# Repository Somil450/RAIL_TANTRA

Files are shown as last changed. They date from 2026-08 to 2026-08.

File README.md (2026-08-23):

# 🚂 Smart Train 3D — Complete Electric Locomotive Assembly Kit

> A fully parametric, 3D-printable modern electric train designed with **CadQuery**.
> The complete 3-car configuration (Locomotive + 2 Wagons) fits within **588 mm** total length.

---

## 📸 Preview


> present in output/SMART_TRAIN_FINAL.step



> present in output/COMPLETE_TRAIN_V3_OPENROOF.step

---

## 🎯 Design Goals

| Goal | Value |
|---|---|
| Total assembled length | ≤ 600 mm → **588 mm** ✅ |
| Locomotive length | 200 mm |
| Each wagon length | 180 mm |
| Inter-vehicle gap | 14 mm (coupler space) |
| Body width | **102 mm (10.2 cm)** |
| Body height | **~102 mm (10.2 cm)** |
| Wheel diameter | **15 mm (1.5 cm)** |
| Roof | **OPEN** (accessible interior) |
| Wheel motion | Spinning (free on axle) |
| Bogie motion | Rotating pivot-pin (for curves) |
| Vehicle connection | Articulated drawbar + pivot bracket |

---

## 🏗️ Design & Architecture

### How we built it

The train was designed **iteratively** using Python + [CadQuery](https://cadquery.readthedocs.io/) — a parametric 3D CAD scripting library. All geometry is defined through master parameters at the top of each script, making it easy to resize any part.

#### Evolution of the design:

```
v1  →  Individual component files (chassis.py, wheel.py, etc.)
v2  →  Merged single-file assembly (COMPLETE_TRAIN_V2)
v3  →  Open roof, wider body (102mm) — COMPLETE_TRAIN_V3
v4  →  Separate movable-wheel files (TRAIN_BODY + WHEEL + AXLE)
v5  →  J-hook couplers, single merged file (FINAL_TRAIN)
v6  →  Full assembly kit: rotating bogies + pivot-drawbar couplers
```

### Key mechanical decisions

#### 1. Rotating Bogies (for cornering)
Each bogie has a **12 mm pivot pin** that sticks up through a **12.4 mm hole** in the chassis underframe. The 0.2 mm clearance per side lets the bogie swivel freely, so the train can navigate curves.

```
Chassis floor (Z = 0)
   ┌──────[12.4mm hole]──────┐
   │                         │
   └─────────────────────────┘
              ↕ swivels
   ┌──────[12.0mm pin]───────┐   ← bogie pivot pin
   │       BOGIE FRAME       │
   │  ┌─leg─┐         ┌─leg─┐│
   │  │axle │ ← → axle│     ││
   │  └─────┘         └─────┘│
   └─────────────────────────┘
        O   O           O   O    ← wheels (15mm dia)
```

#### 2. Articulated Drawbar Coupler (instead of rigid joints)
Between each pair of vehicles:

```
LOCO end ──[pivot bracket]──[drawbar]──[pivot bracket]── WAGON end
              ↑ 5mm pin                  ↑ 5mm pin
              ↓ 5.4mm fork hole          ↓ 5.4mm fork hole
```

- The **pivot bracket** mounts on the inner vehicle face with a 5 mm vertical pin
- The **drawbar** has fork holes (5.4 mm = 0.2 mm clearance → rotates freely)
- A thin mid-section on the drawbar acts as a **flex spring** for slight buffer action

#### 3. Spinning Wheels (FDM clearance)

| Component | Diameter | Fit type |
|---|---|---|
| Axle shaft | 5.0 mm | — |
| Bogie axle-box hole | 5.0 mm nominal | Press-fit (tight) |
| Wheel bore | 5.8 mm | +0.4 mm clearance → **spins freely** |
| Bogie pivot pin | 12.0 mm | — |
| Chassis pivot hole | 12.4 mm | +0.2 mm → **rotates freely** |

---

## 📁 File Structure

```
smart_train_3d/
│
├── 📄 README.md                  ← This file
├── 📄 requirements.txt           ← Python dependencies
│
├── 🐍 SCRIPTS — Build scripts (run these to generate STL/STEP)
│   ├── build_assembly_kit.py     ← ⭐ RECOMMENDED: Generates all 7 separate parts
│   ├── build_final_train.py      ← Single merged file (J-hooks, open roof)
│   ├── build_movable_wheels.py   ← Body + separate wheel + axle files
│   ├── build_complete_train_v3.py← Open roof, 102mm wide, single file
│   ├── build_complete_train_v2.py← Full closed train, single merged file
│   └── build_assembled_train.py  ← Earlier assembled version
│
├── 🐍 COMPONENT MODULES (used by early build scripts)
│   ├── parameters.py             ← All master dimensions
│   ├── chassis.py                ← Chassis underframe
│   ├── body_shell.py             ← Main body shell
│   ├── front_cab.py              ← Aerodynamic cab nose
│   ├── roof.py                   ← Roof panels + HVAC housings
│   ├── bogie.py                  ← Bogie frame geometry
│   ├── wheel.py                  ← Wheel disc + flange
│   ├── axle.py                   ← Axle shaft
│   ├── bearing_housing.py        ← Axle bearing blocks
│   ├── suspension.py             ← Suspension bolster
│   ├── brakes.py                 ← Brake shoe geometry
│   ├── coupler.py                ← Coupler head geometry
│   ├── pantograph.py             ← Roof pantograph structure
│   ├── internal_frame.py         ← Internal structural frame
│   └── TrainLayout.fs            ← Onshape FeatureScript (alternative CAD)
│
└── 📦 output/                    ← All generated STL and STEP files
    │
    ├── 🏆 FINAL / RECOMMENDED FILES
    │   ├── FINAL_TRAIN.stl       ← Complete train, J-hooks, open roof, 15mm wheels
    │   ├── FINAL_TRAIN.step      ← Same, in STEP format (Onshape/Fusion 360)
    │   ├── TRAIN_BODY.stl        ← Body only (no wheels) — for separate-parts printing
    │   ├── WHEEL_15mm.stl        ← Single 15mm wheel — print 24×
    │   └── AXLE_88mm.stl         ← Single axle — print 12×
    │
    ├── 🔄 VERSION HISTORY
    │   ├── COMPLETE_TRAIN_V3_OPENROOF.stl  ← V3: open roof, 102mm wide
    │   ├── COMPLETE_TRAIN_V3_OPENROOF.step
    │   ├── COMPLETE_TRAIN_V2.stl           ← V2: closed roof, 22 parts merged
    │   ├── COMPLETE_TRAIN_V2.step
    │   ├── SMART_TRAIN_COMPLETE.stl        ← V1: original assembled train
    │   └── SMART_TRAIN_COMPLETE.step
    │
    └── 🔩 INDIVIDUAL LOCO COMPONENTS (V1 separate parts)
        ├── 01_chassis.stl / .step
        ├── 02_internal_frame.stl / .step
        ├── 03_body_shell.stl / .step
        ├── 04_front_cab.stl / .step
        ├── 05_roof.stl / .step
        ├── 06_bogie.stl / .step
        ├── 07_wheel.stl / .step
        ├── 08_axle.stl / .step
        ├── 09_bearing_housing.stl / .step
        ├── 10_suspension.stl / .step
        ├── 11_brakes.stl / .step
        ├── 12_coupler.stl / .step
        └── 13_pantograph.stl / .step
```

---

## 🚀 How to Run It Yourself

### Prerequisites

- **Python 3.9+**  (tested on 3.10 and 3.11)
- **CadQuery 2.3+**

### Step 1 — Clone the repo

```bash
git clone https://github.com/Somil450/smart_train_3d.git
cd smart_train_3d
```

### Step 2 — Install dependencies

**Option A — pip (simplest):**
```bash
pip install -r requirements.txt
```

**Option B — conda (if pip fails on Windows):**
```bash
conda install -c conda-forge -c cadquery cadquery
```

### Step 3 — Generate the STL files

**To get the full final train in one file:**
```bash
python build_final_train.py
```
→ Outputs `output/FINAL_TRAIN.stl` and `output/FINAL_TRAIN.step`

**To get separate printable parts (recommended for assembly):**
```bash
python build_assembly_kit.py
```
→ Outputs `output/kit/` with 7 separate part files

**To get body + separate spinning wheels:**
```bash
python build_movable_wheels.py
```
→ Outputs `TRAIN_BODY.stl`, `WHEEL_15mm.stl`, `AXLE_88mm.stl`

### Step 4 — Open in 3D Viewer

On **Windows**, just double-click any `.stl` file — Windows 3D Viewer opens automatically.

Or import the `.step` file into:
- [Onshape](https://www.onshape.com) (free, browser-based)
- [Fusion 360](https://www.autodesk.com/products/fusion-360)
- [FreeCAD](https://www.freecad.org) (free, desktop)

---

## 🖨️ 3D Printing Guide

### Which file to print?

| Use case | File | Count |
|---|---|---|
| Quick single-piece print | `FINAL_TRAIN.stl` | 1× |
| Full assembly with spinning wheels | `TRAIN_BODY.stl` + `WHEEL_15mm.stl` + `AXLE_88mm.stl` | 1× + 24× + 12× |
| Full articulated kit (rotating bogies) | Run `build_assembly_kit.py` → print all 7 parts | See table below |

### Assembly kit print counts

| File | Part | Print |
|---|---|---|
| `01_LOCO_BODY.stl` | Locomotive body (open top) | 1× |
| `02_WAGON_BODY.stl` | Wagon body (identical for both wagons) | 2× |
| `03_BOGIE_FRAME.stl` | Rotating bogie with pivot pin | 6× |
| `04_WHEEL_15mm.stl` | 15 mm wheel disc | 24× |
| `05_AXLE.stl` | 88 mm axle shaft | 12× |
| `06_PIVOT_BRACKET.stl` | Coupler mounting bracket | 4× |
| `07_DRAWBAR.stl` | Articulating drawbar (flex spring) | 2× |

### Recommended print settings

| Setting | Value |
|---|---|
| Layer height | 0.2 mm |
| Infill | 20–30 % |
| Perimeters | 3 |
| Material | PLA or PETG |
| Supports | Required for bogie legs and coupler brackets |
| Bed adhesion | Brim recommended |

### Assembly order

```
Step 1 → Press axle into bogie axle-box holes        (5mm shaft → 5mm hole, tight grip)
Step 2 → Slide 2 wheels onto each axle end            (5.8mm bore → spins on 5mm axle)
Step 3 → Insert bogie pivot pin up into chassis hole  (12mm pin → 12.4mm hole, swivels)
Step 4 → Mount pivot brackets on inner vehicle ends
Step 5 → Clip drawbar fork holes onto bracket pins    (5.4mm hole → 5mm pin, rotates)
Step 6 → Repeat for both inter-vehicle junctions
```

---

## 🔧 Customising Dimensions

All master parameters are at the top of each build script. Key ones:

```python
TW   = 102     # Body width (Y), mm
WD   = 15      # Wheel diameter, mm
GA   = 62      # Track gauge (wheel inner face to inner face), mm
LL   = 200     # Locomotive length, mm
WL   = 180     # Wagon length, mm
GAP  = 14      # Inter-vehicle gap, mm
WALL = 3.0     # Body wall thickness, mm
AZ   = -24     # Axle centre Z (below chassis), mm
```

Change any of these and re-run the script — all geometry rebuilds automatically.

---

## 📐 Final Dimensions

```
┌───────────────────────────────────────────────────────────────┐
│  LOCO (200mm)  │ 14mm │  WAGON 1 (180mm)  │ 14mm │  WAGON 2  │
│                │      │                   │      │  (180mm)  │
└───────────────────────────────────────────────────────────────┘
                         ◄────────── 588 mm total ────────────►

Width:  102 mm (10.2 cm)
Height: ~102 mm (10.2 cm)
Wheel:   15 mm diameter (1.5 cm)
```

---

## 🛠️ Tech Stack

| Tool | Purpose |
|---|---|
| [Python 3.10](https://www.python.org/) | Scripting language |
| [CadQuery 2.3](https://cadquery.readthedocs.io/) | Parametric 3D CAD kernel |
| [OCC (OpenCASCADE)](https://www.opencascade.com/) | Underlying BREP geometry engine |
| [Onshape](https://www.onshape.com) | Cloud CAD viewer / assembly |
| Windows 3D Viewer | Quick STL preview |

---

## 📋 GitHub Repo

🔗 **[https://github.com/Somil450/smart_train_3d](https://github.com/Somil450/smart_train_3d)**

---

## 📜 License

This project is open source — use, modify, and 3D-print freely. Attribution appreciated!

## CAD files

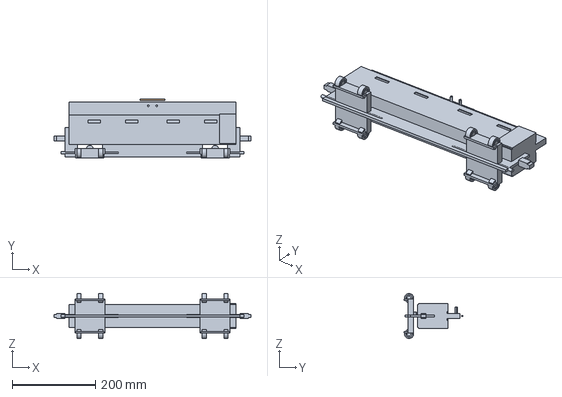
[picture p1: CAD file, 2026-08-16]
output/SMART_TRAIN_COMPLETE.step
472.0 x 141.0 x 108.0 mm

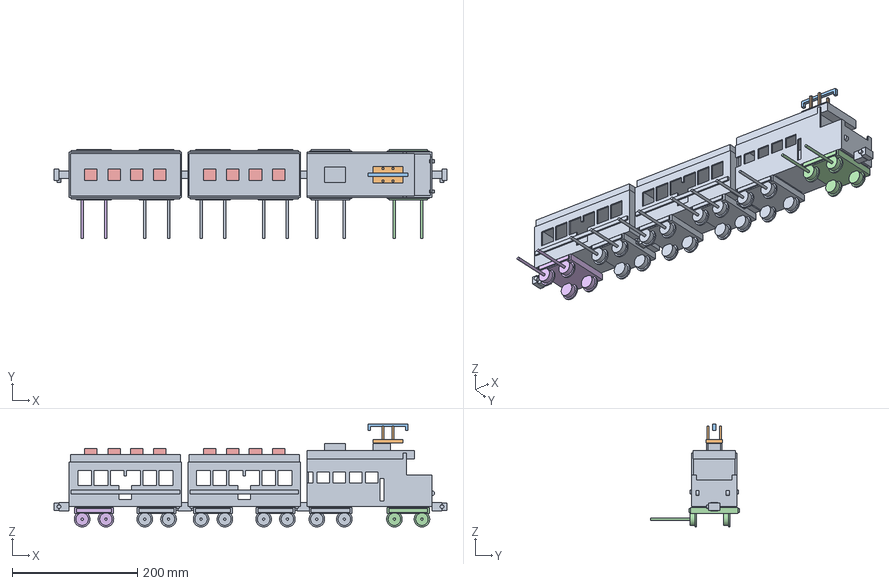
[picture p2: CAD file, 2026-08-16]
output/COMPLETE_TRAIN_V2.step
628.0 x 142.5 x 164.5 mm

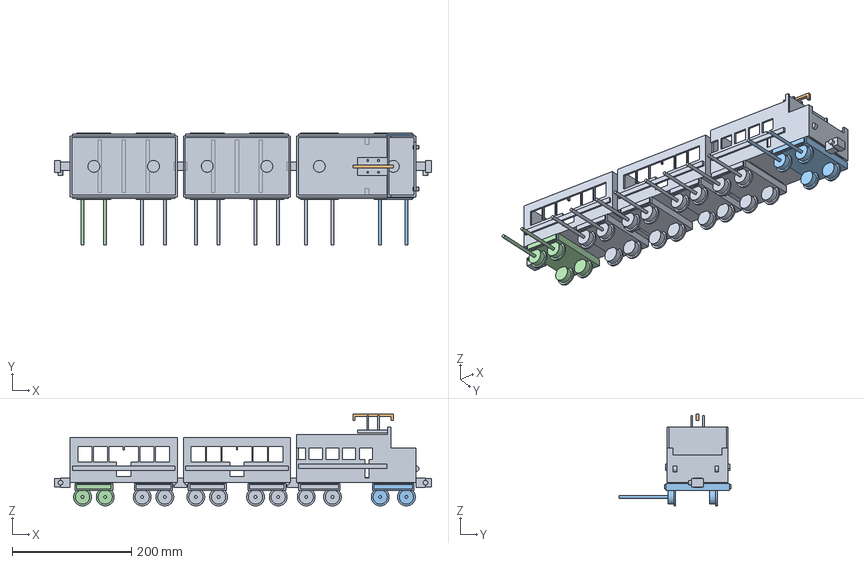
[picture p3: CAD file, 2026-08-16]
output/COMPLETE_TRAIN_V3_OPENROOF.step
632.0 x 188.0 x 154.0 mm

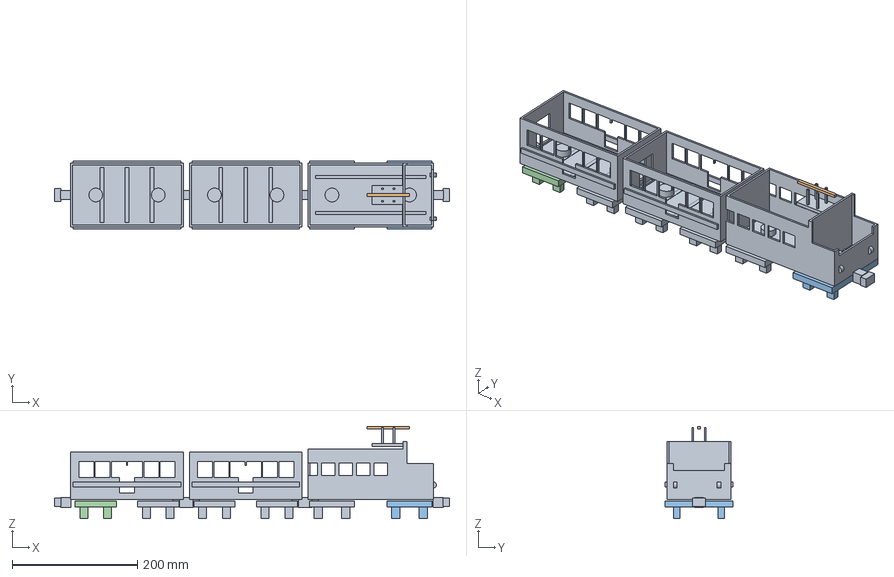
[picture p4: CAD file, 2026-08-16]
output/TRAIN_BODY.step
632.0 x 108.0 x 147.5 mm

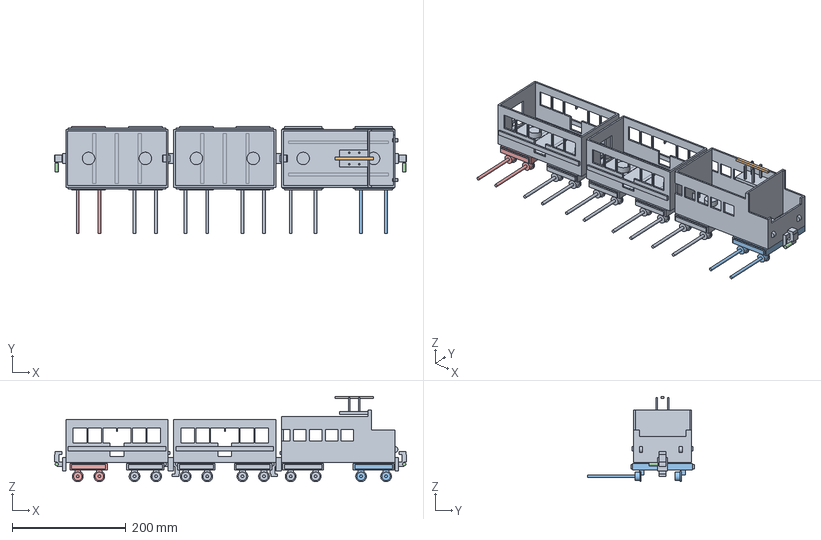
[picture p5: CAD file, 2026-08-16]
output/FINAL_TRAIN.step
620.0 x 188.0 x 150.5 mm

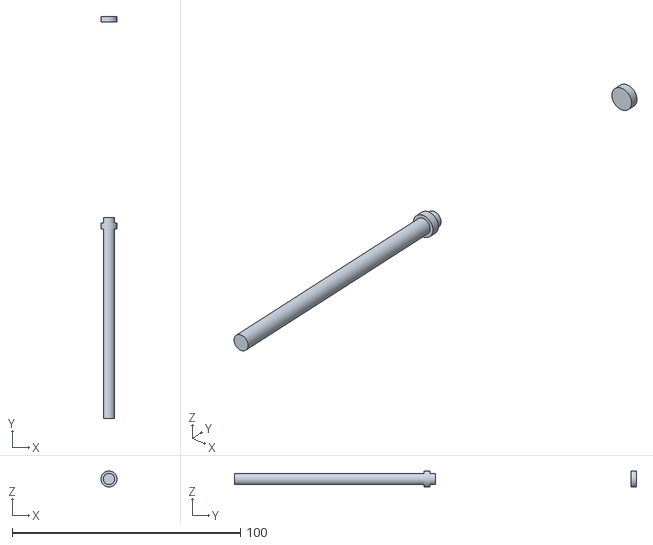
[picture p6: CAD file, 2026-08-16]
output/AXLE_88mm.stl
7.00 x 176.0 x 7.00

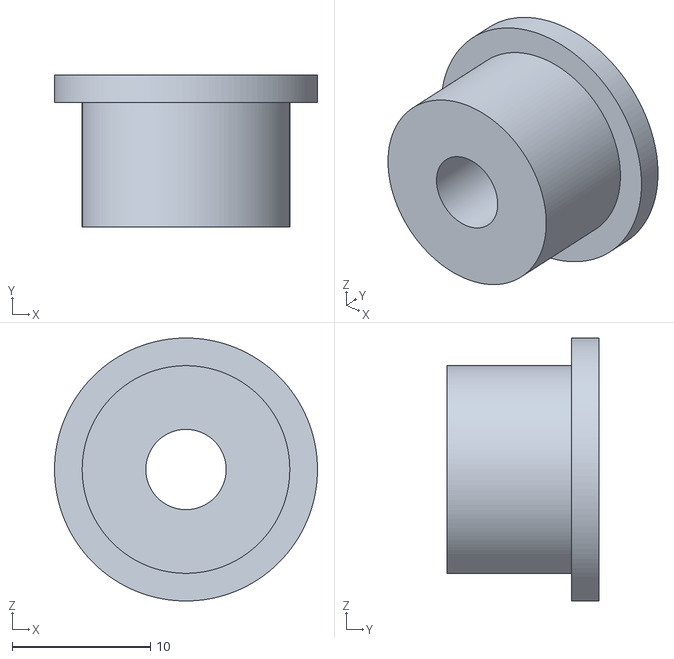
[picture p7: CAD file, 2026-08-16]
output/WHEEL_15mm.stl
19.0 x 11.0 x 19.0

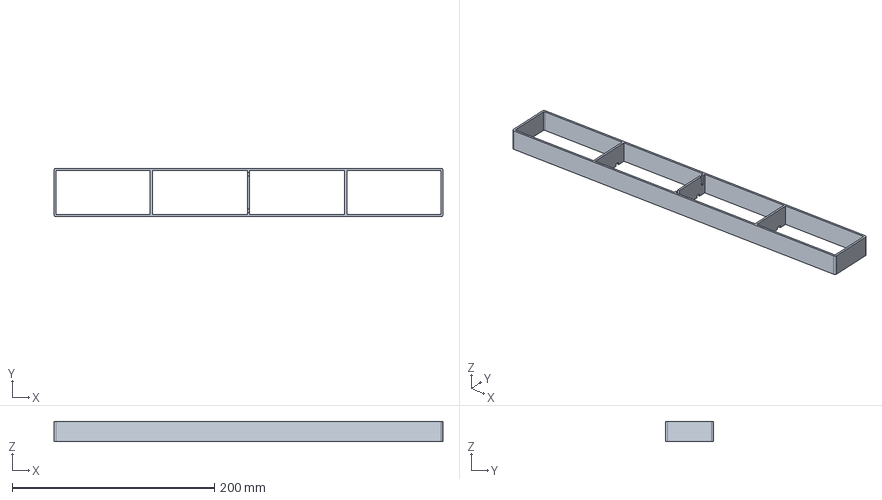
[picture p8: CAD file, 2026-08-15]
output/02_internal_frame.step
385.0 x 48.0 x 20.0 mm

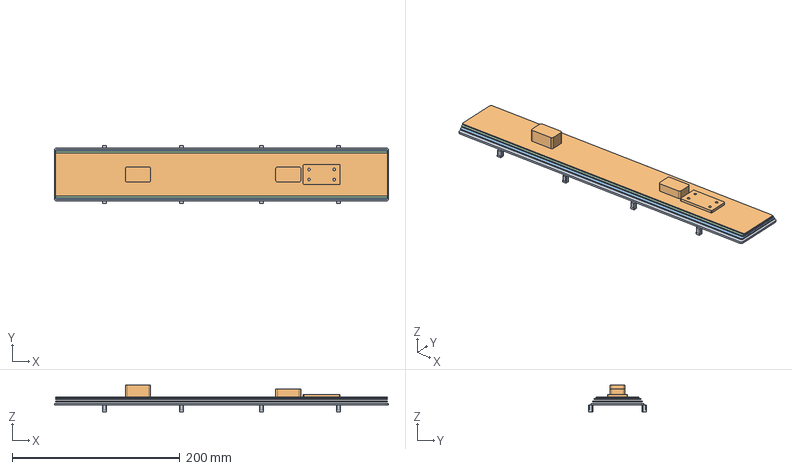
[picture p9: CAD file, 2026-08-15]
output/05_roof.step
398.0 x 69.2 x 32.0 mm

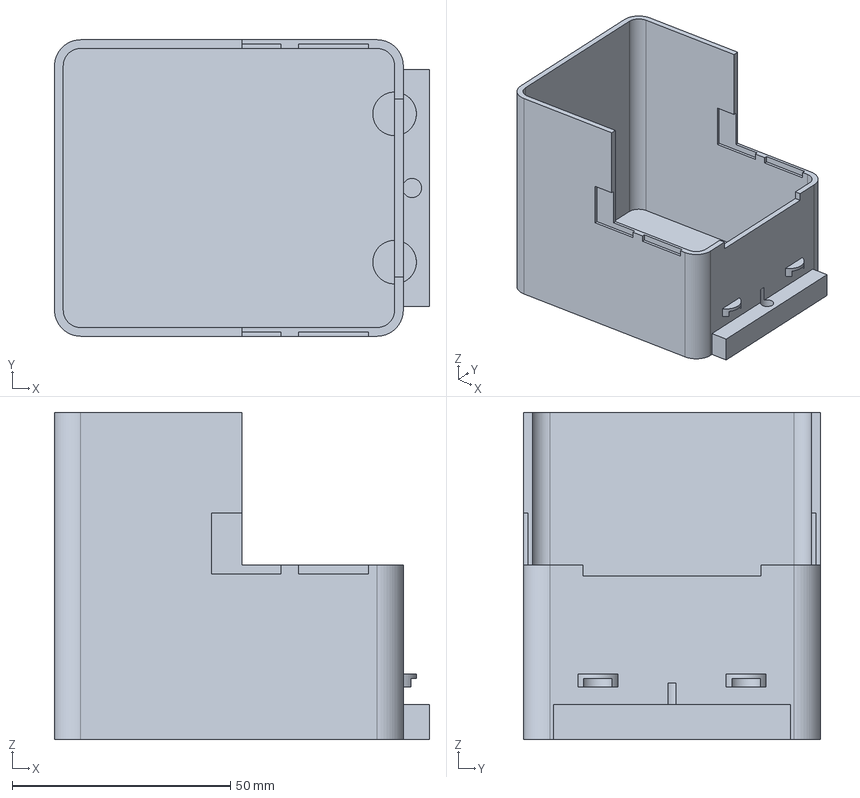
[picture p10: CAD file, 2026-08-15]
output/04_front_cab.step
86.0 x 68.0 x 75.0 mm

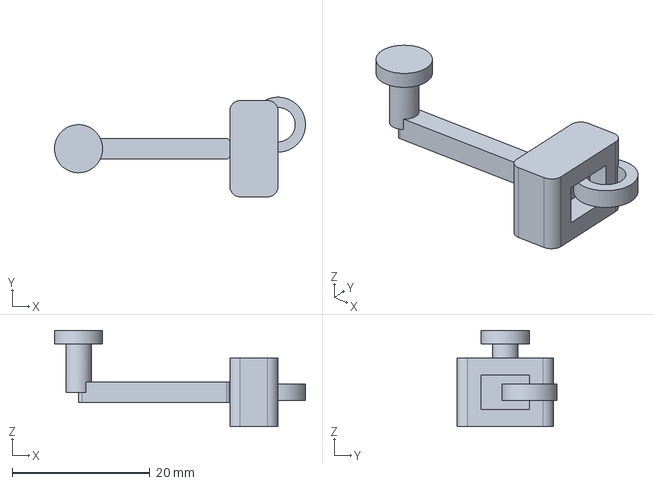
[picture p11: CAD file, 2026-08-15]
output/12_coupler.step
36.5 x 14.5 x 14.0 mm

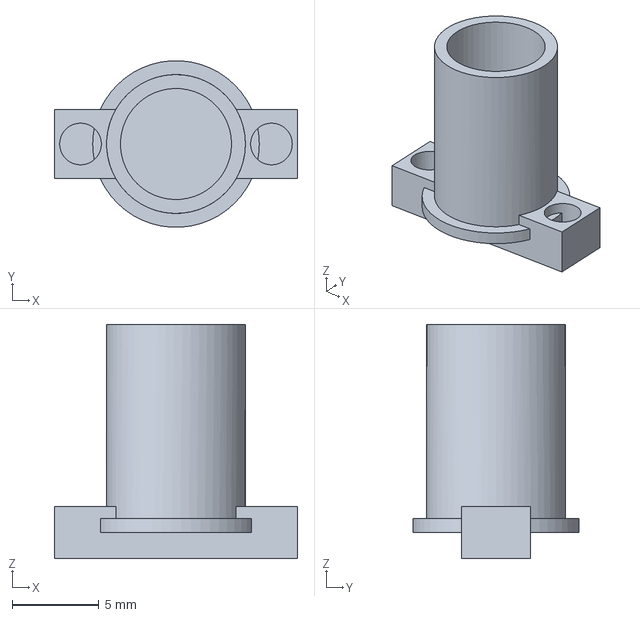
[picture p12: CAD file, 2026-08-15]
output/10_suspension.step
14.0 x 9.58 x 13.5 mm

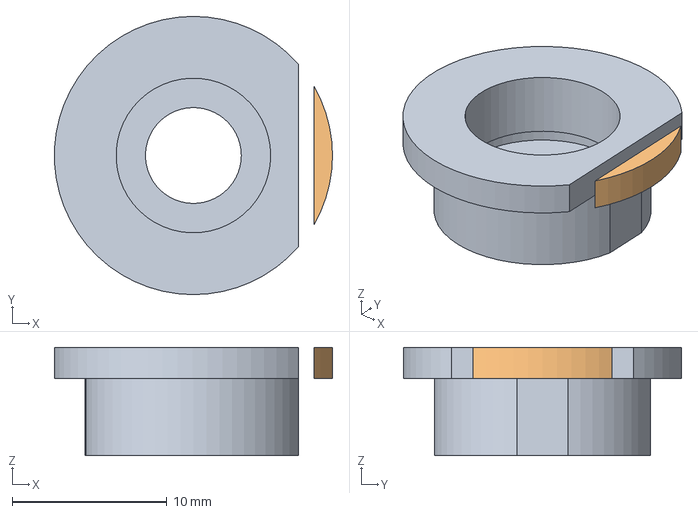
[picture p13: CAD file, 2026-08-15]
output/09_bearing_housing.step
18.0 x 18.0 x 7.00 mm

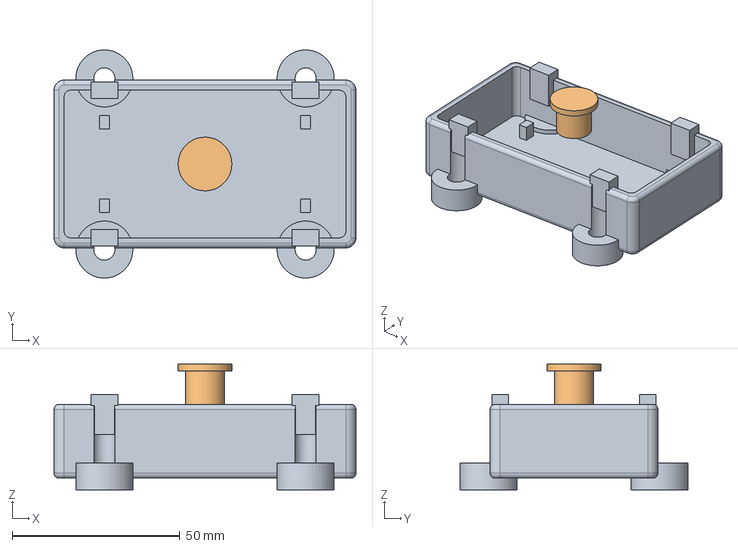
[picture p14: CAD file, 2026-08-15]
output/06_bogie.step
90.0 x 68.0 x 37.5 mm

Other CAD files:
output/07_wheel.step
output/01_chassis.step
output/13_pantograph.step
output/03_body_shell.step
output/01_chassis.stl
output/02_internal_frame.stl
output/03_body_shell.stl
output/04_front_cab.stl
output/05_roof.stl
output/06_bogie.stl
output/07_wheel.stl
output/08_axle.step
output/08_axle.stl
output/09_bearing_housing.stl
output/10_suspension.stl
output/11_brakes.step
output/11_brakes.stl
output/12_coupler.stl
output/13_pantograph.stl
output/COMPLETE_TRAIN_V2.stl
output/COMPLETE_TRAIN_V3_OPENROOF.stl
output/FINAL_TRAIN.stl
output/SMART_TRAIN_COMPLETE.stl
output/TRAIN_BODY.stl

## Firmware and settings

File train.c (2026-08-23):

#include <WiFi.h>
#include <esp_now.h>
#include "esp_wifi.h"

// =====================================
// L298N MOTOR PINS
// =====================================

// MOTOR 1
#define IN1 25
#define IN2 26

// MOTOR 2
#define IN3 27
#define IN4 14


// =====================================
// MOTOR 1
// =====================================

void motor1Stop() {
  digitalWrite(IN1, LOW);
  digitalWrite(IN2, LOW);
}

void motor1Forward() {

  // Stop first
  motor1Stop();
  delay(10);

  digitalWrite(IN1, HIGH);
  digitalWrite(IN2, LOW);
}

void motor1Backward() {

  // Stop first
  motor1Stop();
  delay(10);

  digitalWrite(IN1, LOW);
  digitalWrite(IN2, HIGH);
}


// =====================================
// MOTOR 2
// =====================================

void motor2Stop() {
  digitalWrite(IN3, LOW);
  digitalWrite(IN4, LOW);
}

void motor2Forward() {

  // Stop first
  motor2Stop();
  delay(10);

  digitalWrite(IN3, HIGH);
  digitalWrite(IN4, LOW);
}

void motor2Backward() {

  // Stop first
  motor2Stop();
  delay(10);

  digitalWrite(IN3, LOW);
  digitalWrite(IN4, HIGH);
}


// =====================================
// STOP BOTH MOTORS
// =====================================

void stopAllMotors() {

  motor1Stop();
  motor2Stop();
}


// =====================================
// RECEIVE ESP-NOW DATA
// =====================================

void receiveData(
  const esp_now_recv_info_t *info,
  const uint8_t *data,
  int len
) {

  // We expect exactly 1 byte
  if (len != 1) {
    Serial.println("INVALID DATA");
    return;
  }

  char command = data[0];

  Serial.print("RECEIVED: ");
  Serial.println(command);


  // ===================================
  // MOTOR 1 FORWARD
  // A
  // ===================================

  if (command == 'A' || command == 'a') {

    Serial.println("MOTOR 1 FORWARD");

    // Keep motor 2 stopped
    motor2Stop();

    // Motor 1 forward
    motor1Forward();
  }


  // ===================================
  // MOTOR 1 BACKWARD
  // B
  // ===================================

  else if (command == 'B' || command == 'b') {

    Serial.println("MOTOR 1 BACKWARD");

    // Keep motor 2 stopped
    motor2Stop();

    // Motor 1 backward
    motor1Backward();
  }


  // ===================================
  // MOTOR 2 FORWARD
  // C
  // ===================================

  else if (command == 'C' || command == 'c') {

    Serial.println("MOTOR 2 FORWARD");

    // Keep motor 1 stopped
    motor1Stop();

    // Motor 2 forward
    motor2Forward();
  }


  // ===================================
  // MOTOR 2 BACKWARD
  // D
  // ===================================

  else if (command == 'D' || command == 'd') {

    Serial.println("MOTOR 2 BACKWARD");

    // Keep motor 1 stopped
    motor1Stop();

    // Motor 2 backward
    motor2Backward();
  }


  // ===================================
  // STOP
  // =====================================

  else if (command == 'S' || command == 's') {

    Serial.println("STOP");

    stopAllMotors();
  }


  // ===================================
  // UNKNOWN COMMAND
  // ===================================

  else {

    Serial.println("UNKNOWN COMMAND");

    stopAllMotors();
  }
}


// =====================================
// SETUP
// =====================================

void setup() {

  Serial.begin(115200);


  // ===================================
  // L298N PINS
  // ===================================

  pinMode(IN1, OUTPUT);
  pinMode(IN2, OUTPUT);

  pinMode(IN3, OUTPUT);
  pinMode(IN4, OUTPUT);


  // ===================================
  // MOTORS OFF
  // ===================================

  stopAllMotors();


  // ===================================
  // WIFI
  // ===================================

  WiFi.mode(WIFI_STA);

  // Same channel as transmitter
  esp_wifi_set_channel(1, WIFI_SECOND_CHAN_NONE);


  // ===================================
  // INFORMATION
  // ===================================

  Serial.println();
  Serial.println("==============================");
  Serial.println("ESP32 #2 MOTOR RECEIVER");
  Serial.println("==============================");

  Serial.print("MAC: ");
  Serial.println(WiFi.macAddress());


  // ===================================
  // ESP-NOW
  // ===================================

  if (esp_now_init() != ESP_OK) {

    Serial.println("ESP-NOW INIT FAILED!");

    stopAllMotors();

    while (true) {
      delay(1000);
    }
  }


  // ===================================
  // REGISTER RECEIVE CALLBACK
  // ===================================

  esp_now_register_recv_cb(receiveData);


  Serial.println("ESP-NOW READY");
  Serial.println("WAITING FOR COMMANDS...");
  Serial.println();
}


// =====================================
// LOOP
// =====================================

void loop() {

  // NOTHING HERE

  // Motors continue running until
  // another command is received.

  delay(10);
}

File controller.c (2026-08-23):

#include <WiFi.h>
#include <esp_now.h>
#include "esp_wifi.h"

// =====================================
// BUTTON PINS
// =====================================

#define RED1    32
#define BLACK1  33
#define RED2    18
#define BLACK2  19


// =====================================
// BROADCAST ADDRESS
// =====================================

uint8_t receiverAddress[] = {
  0xFF,
  0xFF,
  0xFF,
  0xFF,
  0xFF,
  0xFF
};


// =====================================
// SEND COMMAND
// =====================================

void sendCommand(char command) {

  esp_err_t result = esp_now_send(
    receiverAddress,
    (uint8_t *)&command,
    1
  );

  if (result == ESP_OK) {

    Serial.print("SENT: ");
    Serial.println(command);

  } else {

    Serial.print("SEND ERROR: ");
    Serial.println(result);
  }
}


// =====================================
// SETUP
// =====================================

void setup() {

  Serial.begin(115200);


  // ===================================
  // BUTTONS
  // ===================================

  pinMode(RED1, INPUT_PULLUP);
  pinMode(BLACK1, INPUT_PULLUP);
  pinMode(RED2, INPUT_PULLUP);
  pinMode(BLACK2, INPUT_PULLUP);


  // ===================================
  // WIFI
  // ===================================

  WiFi.mode(WIFI_STA);

  esp_wifi_set_channel(
    1,
    WIFI_SECOND_CHAN_NONE
  );


  // ===================================
  // MAC
  // ===================================

  Serial.println();
  Serial.println("==============================");
  Serial.println("ESP32 #1 CONTROLLER");
  Serial.println("==============================");

  Serial.print("MAC: ");
  Serial.println(WiFi.macAddress());


  // ===================================
  // ESP-NOW
  // ===================================

  if (esp_now_init() != ESP_OK) {

    Serial.println("ESP-NOW INIT FAILED!");

    while (true) {
      delay(1000);
    }
  }


  // ===================================
  // ADD BROADCAST PEER
  // ===================================

  esp_now_peer_info_t peerInfo = {};

  memcpy(
    peerInfo.peer_addr,
    receiverAddress,
    6
  );

  peerInfo.channel = 1;
  peerInfo.encrypt = false;


  if (esp_now_add_peer(&peerInfo) != ESP_OK) {

    Serial.println("FAILED TO ADD PEER!");

    while (true) {
      delay(1000);
    }
  }


  Serial.println("ESP-NOW READY");
  Serial.println("CONTROLLER READY");
}


// =====================================
// LOOP
// =====================================

void loop() {

  // ===================================
  // RED 1
  // ===================================

  if (digitalRead(RED1) == LOW) {

    sendCommand('A');
  }


  // ===================================
  // BLACK 1
  // ===================================

  else if (digitalRead(BLACK1) == LOW) {

    sendCommand('B');
  }


  // ===================================
  // RED 2
  // ===================================

  else if (digitalRead(RED2) == LOW) {

    sendCommand('C');
  }


  // ===================================
  // BLACK 2
  // ===================================

  else if (digitalRead(BLACK2) == LOW) {

    sendCommand('D');
  }


  // ===================================
  // NO BUTTON
  // ===================================

  else {

    sendCommand('S');
  }


  // Send every 100 ms
  delay(100);
}

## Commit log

2026-08-16 update the whole code
    [AXLE_88mm.stl, COMPLETE_TRAIN_V2.step, COMPLETE_TRAIN_V2.stl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]
2026-08-16 docs: add comprehensive README with design guide, file map & print instructions
2026-08-23 Update README with image previews and viewing instructions
    Added image previews and instructions for STL file viewing.
2026-08-23 Remove FINAL TRAIN image link from README
    Removed the image link for the FINAL TRAIN — 3 Views.
